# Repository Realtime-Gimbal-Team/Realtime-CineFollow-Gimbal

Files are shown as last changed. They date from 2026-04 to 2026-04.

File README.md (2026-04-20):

# Realtime-CineFollow-Gimbal

<div align="center">
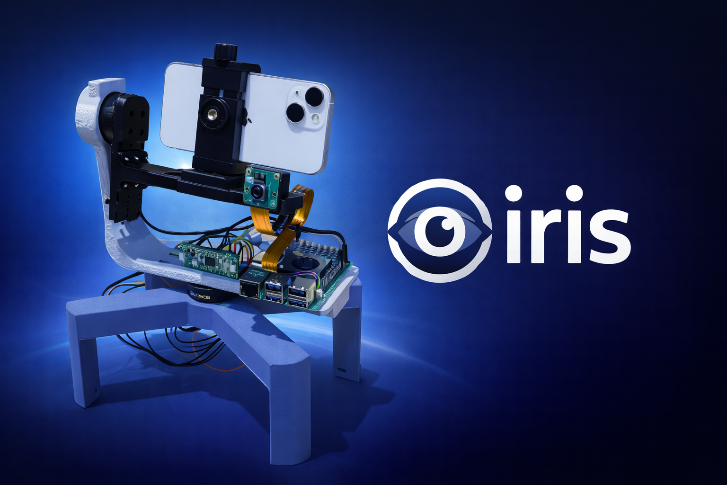
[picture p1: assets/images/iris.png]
  
  <h1>👁️ IRIS</h1>
  <p><b>Real-time Intelligent Cine-Follow Gimbal</b></p>
  <p><i>The autonomous, real-time camera operator for solo content creators.</i></p>

  <p>
    <a href="https://realtime-gimbal-team.github.io/CineFollow-Docs/">
      
    </a>
    <a href="./docs/Final_Technical_Report.pdf">
      
    </a>
    <a href="https://vm.tiktok.com/ZNRq9RjLb/">
      
    </a>
  </p>

  <p>
    <a href="./assets/3d_models/">
      
    </a>
    <a href="https://www.tiktok.com/@embedded629">
      
    </a>
  </p>
</div>

---

### 📖 Quick Navigation
> **Project for ENG 5220: Real Time Embedded Programming @ University of Glasgow**
> 
> [🌐 Online Manual](https://realtime-gimbal-team.github.io/CineFollow-Docs/) | [📄 Read Final Technical Report](./docs/) | [📦 Download 3D Print Models](./assets/3d_models/) | [🎬 Demo Video (TikTok)](https://vm.tiktok.com/ZNRq9RjLb/) | 

---
---

## **📌 Project Overview**

**IRIS** is a high-performance, dual-axis cine-follow gimbal engineered to solve the "solo shooter" problem. By offloading complex tracking and stabilization tasks to an autonomous embedded system, IRIS allows creators to remain the focus of their story without needing a human camera operator.

The project is built on the **Raspberry Pi 5** platform, pushing the boundaries of real-time computer vision and motion control in a mobile form factor.

### 🛠️ Core Engineering Philosophy

1.  **Low-Level Camera Integration (`libcamera`)**: 
    We implemented a high-efficiency camera interface by **strictly adhering to the standard `libcamera` framework** recommended for the Raspberry Pi 5. By encapsulating the professor's prescribed C++ interface logic, we achieved seamless V4L2-level buffer management, ensuring that the OpenCV vision node receives raw frames with minimal kernel-to-userspace overhead.
2.  **Deterministic Control Logic**: 
    The system operates on a **100Hz deterministic control loop**. By utilizing `std::this_thread::sleep_until` and monotonic clocks, we ensure the Yaw and Pitch motors receive velocity updates at precise intervals, eliminating jitter caused by scheduling variances.
3.  **Event-Driven Architecture**: 
    Instead of wasteful polling, the IRIS software stack is entirely **event-driven**. Image acquisition triggers asynchronous callbacks, and motor commands are dispatched via non-blocking UART protocols, ensuring the CPU remains responsive to high-priority safety interrupts.
4.  **Hardware-Software Synergy**: 
    From custom 3D-printed axis arms to the SimpleFOC brushless drive implementation, every component is tuned to minimize mechanical resonance and maximize the tracking bandwidth of the Vision Node.

---
## 📸 Prototype

<p align="center">
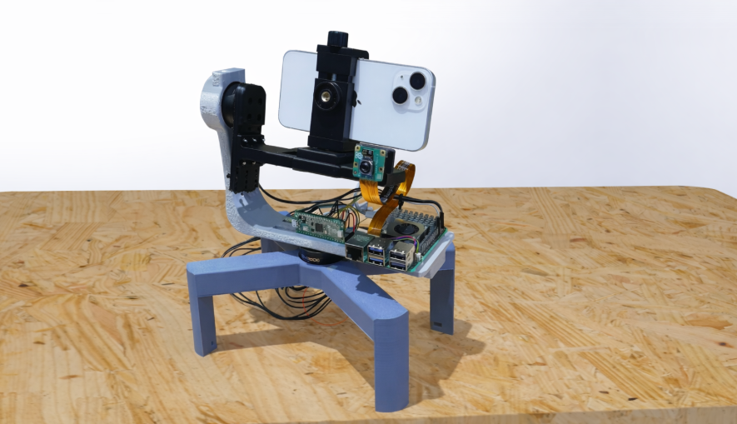
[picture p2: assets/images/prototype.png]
  
</p>

<p align="center">
  <i>Physical prototype of the IRIS real-time cine-follow gimbal system.</i>
</p>

### ⚡ Core Real-Time Requirements & Architecture
- **Strict Real-Time Execution:** This project addresses a solid real-time requirement where any delay in image processing or PID calculation would result in jerky motion or tracking loss. We achieved a **deterministic 100Hz control loop** utilizing `std::this_thread::sleep_until`, completely avoiding blocking polling statements.
- **Event-Driven Architecture:** Utilizes Callbacks and Lambdas to handle frame-ready events (`camera.startCapture`), significantly minimizing polling latency.
- **Multithreading & Memory Safety:** Separated threads for vision acquisition, CV processing, and PID control using `std::thread`. Shared states are strictly protected by `std::mutex`. The system relies entirely on modern C++ (C++17) RAII for failsafe memory management with zero explicit `new/delete` operations.

## System Architecture & Workflow

The Iris Gimbal operates on a high-concurrency, multi-threaded architecture designed to bridge real-time AI perception with fluid mechanical actuation. The system is structured into three primary decoupled threads to ensure ultra-low latency and deterministic control.

<p align="center">
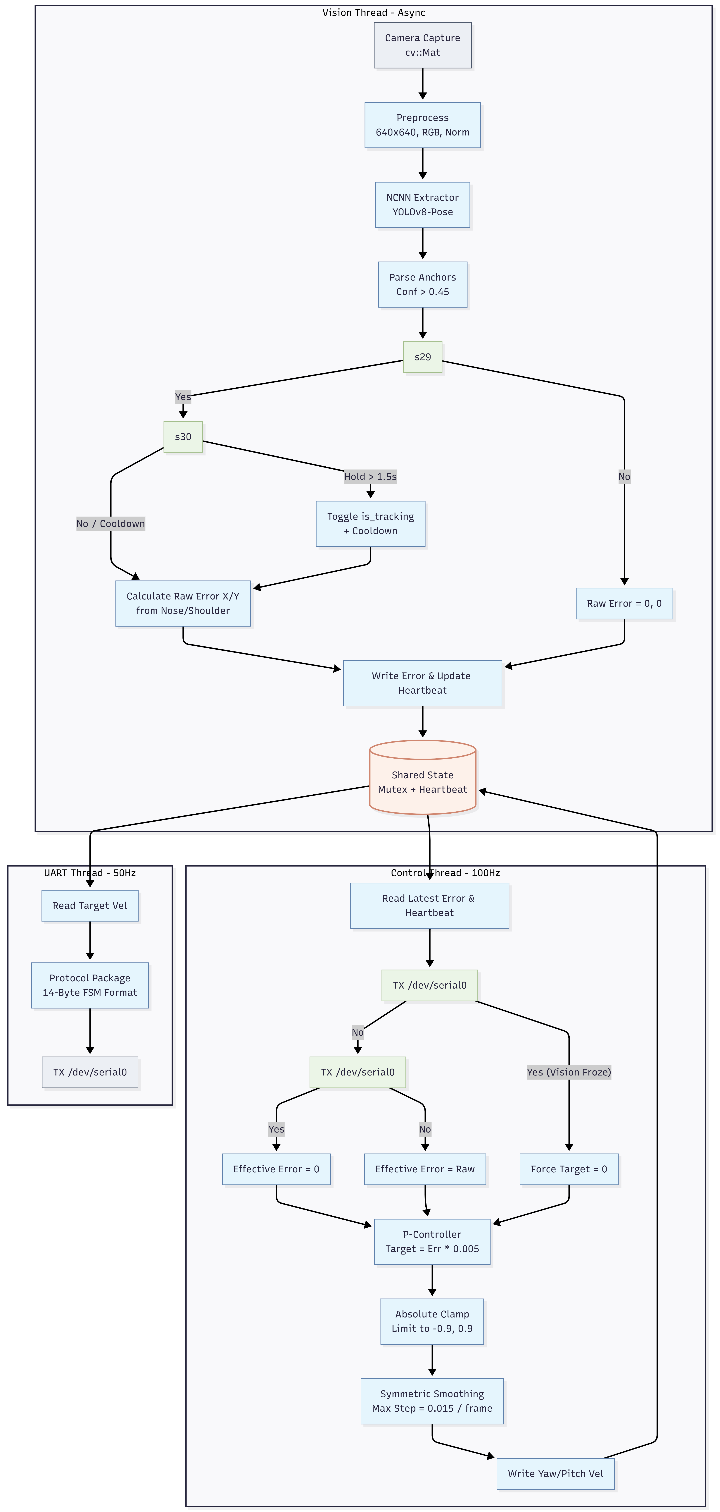
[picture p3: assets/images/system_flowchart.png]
System Flowchart
  
<p align="center">
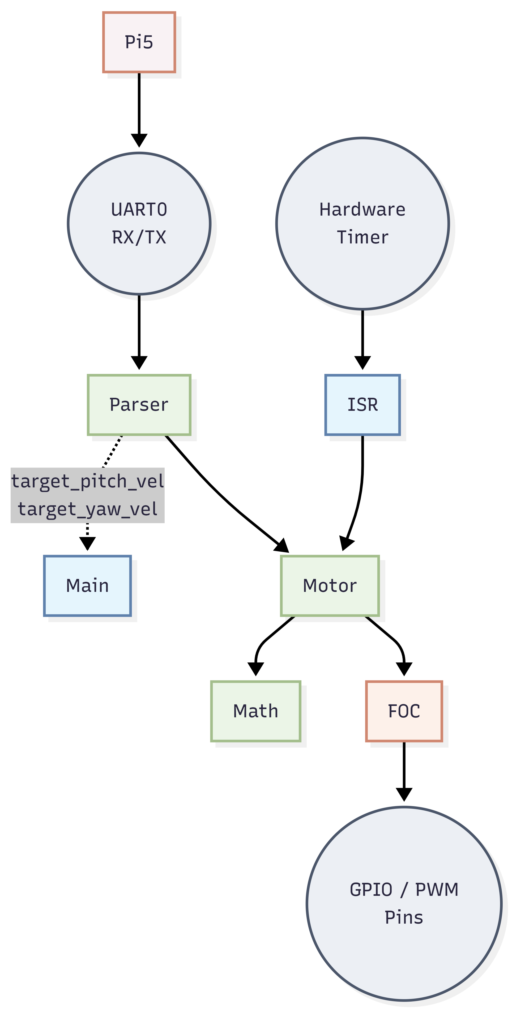
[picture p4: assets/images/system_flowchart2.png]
System Flowchart
  
</p>

### Thread Logic Breakdown:

* **Vision Perception Thread**: Executes YOLOv8-Pose inference (approx. 86ms) on the Raspberry Pi 5. It handles anatomical keypoint anchoring (Nose-point tracking) and manages the **1.5s gesture state machine** for non-contact interaction.
* **Kinematic Control Thread**: Consumes visual error data to calculate target velocities. It utilizes a **Symmetric Step Smoothing** algorithm (step = 0.015) to eliminate high-frequency jitter and ensure cinematic motion profiles.
* **UART Communication Thread**: Encapsulates velocity commands into the transmission protocol and dispatches them to the motor driver at a consistent 50Hz frequency.

## 👉 Division of responsibilities among team members
- **Yining Liu (3153782Y)**: Led system decision-making, visual algorithm development, and core C++ architecture; implemented YOLO deployment, Greedy Distance Matching tracking, Symmetric Soft Ramp control logic, Mutex Threading Architecture, and latency-oriented performance evaluation.
- **Zongwei Xie (3085969X)**: Developed the low-level motor control and hardware execution layer; implemented the motor driver based on SimpleFOC, tuned PID control loops, and handled real-time UART communication and protocol parsing.
- **Yifei Wang (3147822W)**: Responsible for system integration and runtime logic; implemented mode switching and event-driven control, and assisted in debugging and improving system stability.
- **Yandong Fan (3159430F)**: Took charge of reliability engineering and latency assessment; built quantitative timing tools, supported unit testing for core modules, and carried out memory and fault management checks.
- **Chenxu Li (3091645L)**: Managed project coordination, revision control, and external promotion; defined Git branching and issue-tracking workflows, prepared reproducible project documentation, and supported public outreach on social media.

## **🚀 Development Progress**

🔄 Hardware selection & procurement ·····························································································································✅[Completed]

🔄 Initial code framework setup (C++ & sensor drivers) ···································································································✅[Completed]

🔄 Optimization of real-time data processing ····················································································································✅[Completed]

🔄 Enhancing user interaction  ··············································································································································✅[Completed]

🔄 Software testing & debugging ····································································································································✅[Completed]

📢 Project promotion  ·························································································································································✅[Completed]

## 🎯 Key Features

* **✅ Anatomical Keypoint Tracking (YOLOv8-Pose & NCNN)**
    Shifted from traditional bounding-box tracking to 17-keypoint skeletal estimation. By anchoring the tracking logic to the subject’s **Nose (Keypoint 0)**, the system fundamentally solves the "compositional drift" paradox, ensuring stable framing even when the subject's lower body is cropped as they approach the lens.

* **✅ Non-Contact Gesture Interaction (HRI State Machine)**
    Implemented a zero-overhead gesture recognition layer. A robust temporal state machine requires a "raised hand" gesture to be held for **17 frames (~1.5s)** to toggle tracking states, providing a seamless, hands-free operational switch with a built-in 35-frame cooldown to prevent accidental triggers.

* **✅ Smooth Motion Planning (Symmetric Soft Ramp & Deadzone)**
    Camera motion principles are translated into a custom kinematic planner. We implemented a **Symmetric Linear Soft Ramp** (Step = 0.015) and a **Continuous Soft Deadzone** (±12px) to eliminate high-frequency oscillations and cogging torque, achieving cinematic, fluid movement without "sawtooth" jitter.

* **✅ Deterministic Multi-Threaded Architecture**
    The system runs on a decoupled triple-thread C++ architecture (Vision, Control, UART) using `std::mutex` and `std::atomic` for thread safety. This ensures the 86ms vision inference loop never blocks the high-frequency motor control dispatch, ensuring maximum system responsiveness.

* **✅ High-Precision Motor Actuation (SPWM & PID)**
    Brushless motors are driven via a streamlined, bare-metal SPWM execution layer. By extracting core mathematical vectors and bypassing heavy third-party HALs, the system achieves hard real-time, low-vibration actuation directly from the control thread.

* **✅ Real-Time Performance & Latency Profiling**
    Equipped with a custom profiling utility to monitor the full-pipeline delay with microsecond precision. The system maintains a consistent **~86ms end-to-end latency**, validated through extensive real-world tracking scenarios to ensure stability and high-frequency command dispatch (50Hz) via an optimized UART protocol.

## **🔧 Hardware Components**
| Component | Specification | Quantity | Purpose |
| --- | --- | ---: | --- |
| Raspberry Pi Pico 2 | Microcontroller board | 1 | Low-level motor control and embedded task execution |
| Raspberry Pi 5 | Single-board computer | 1 | Main processing unit for vision, control logic, and system coordination |
| Raspberry Pi 5 Active Cooler | Official active cooling module  | 1 | Thermal management for stable Raspberry Pi 5 operation |
| GM3506 Gimbal Motor | Brushless gimbal motor | 2 | Two-axis gimbal actuation for yaw and pitch movement |
| Auline 4800mAh LiPo Battery | Rechargeable LiPo battery | 1 | Portable power supply for the whole system |
| XT60 One-to-Two Cable | XT60 splitter cable | 1 | Power distribution from battery to multiple modules |
| XT60 Cable | Standard XT60 power cable | 1 | Main battery connection and power transmission |
| USB-C 5V Buck Converter Module | DC step-down module | 1 | Converts battery voltage to stable 5V supply for electronics |
| SimpleFOC Mini Dual Driver Board | One-driver-for-two-motors board | 1 | Drives and controls the two gimbal motors |
| Raspberry Pi Camera Module 3 | Official camera module | 1 | Visual input for object detection and tracking |
| Camera Ribbon Cable | CSI camera cable | 1 | Connects Camera Module 3 to Raspberry Pi 5 |
| Dupont Wires | Various jumper wires | - | General signal and power wiring between modules |
| 3D Printed Base | Custom structural part | 1 | Mechanical support for mounting the system components |
| 3D Printed Gimbal Arm | Custom axis arm structure | 1 set | Supports motor installation and gimbal movement |
| XH2.54 5-Pin Cable | 5-pin Dupont/JST-style cable | 1 | Electrical connection between driver board and motors/sensors |
| Phone Clamp | Adjustable holder | 1 | Holds the mobile phone securely on the gimbal platform |
| iPhone 13 mini | Smartphone payload | 1 | Target payload for stabilization and tracking demonstration |
| M2 / M2.5 Screws and Nuts | Fasteners | Assorted | Mechanical assembly and structural fixing |

### 🔧 3D Printed Structural Assets
All custom mechanical components are available in the `/assets/3d_models/` directory for reproduction:
* `iris_base_mount.stl`: Primary mounting stand.
* `iris_yaw_arm_l_shape.stl`: Main Yaw-axis structural arm.
* `iris_pitch_motor_bracket.stl`: Pitch-axis GM3506 motor mounting bracket.
* `iris_payload_plate.stl`: Platform for smartphone/camera payload.

## **💻 How to Reproduce (Build Instructions)**
To ensure maximum reproducibility, follow these steps to build the project on a Raspberry Pi 5 running Linux:

```bash
# 1. Clone the repository
git clone [https://github.com/Realtime-Gimbal-Team/Realtime-CineFollow-Gimbal.git](https://github.com/Realtime-Gimbal-Team/Realtime-CineFollow-Gimbal.git)
cd Realtime-CineFollow-Gimbal

# 2. Create build directory
mkdir build && cd build

# 3. Compile the project
cmake ..
make -j4

# 4. Execute the Real-time Gimbal Node
./Realtime_CineFollow_Gimbal
```

## **💻 Software Architecture**

The software architecture is engineered following **SOLID principles** and the **Sense-Think-Act** paradigm. To meet strict real-time deadlines, the system is horizontally decoupled into independent threads, ensuring that heavy computer vision workloads never block critical motor control loops. 

All hardware communication and shared states are encapsulated in thread-safe classes with private data members, ensuring high reliability and ease of maintenance.

### 📂 Directory Structure & Module Decoupling

```text
📦 Realtime-CineFollow-Gimbal
 ┣ 📂 pico/Pico-firmware/       # Execution Layer: Microcontroller firmware
 ┃ ┣ 📂 SimpleFOC_Core/         # Hardware-level FOC motor driving algorithms
 ┣ ┣ 📂 include/                # Header files
 ┃ ┗ 📂 src/                    # High-frequency PID loop execution
 ┗ 📂 rpi_app/                  # High-Level Logic: Edge AI & Control
   ┣ 📂 3rdparty/ncnn/          # Optimized neural network inference engine
   ┣ 📂 include/                # Header files grouped by SOLID domains
   ┃ ┣ 📂 comm/                 # UartDriver: Serial protocol encapsulation
   ┃ ┣ 📂 control/              # Ramp generators and deadzone logic
   ┃ ┣ 📂 utils/                # SharedState: Thread-safe data brokers
   ┃ ┗ 📂 vision/               # VisionNode: Event-driven camera interface
   ┣ 📂 models/                 # Pre-trained YOLOv8-pose weights
   ┗ 📂 src/                    # Core C++ implementations (main.cpp, libcam interfaces)
```
🧱 Core Subsystems

**Sense**: Event-Driven Vision (vision/VisionNode)
Operating strictly on callbacks, the vision node retrieves zero-copy frame buffers from libcamera. It processes YOLOv8-pose inferences via NCNN and extracts pure pixel errors (target vs. anchor) without blocking the main CPU execution flow.

**Think**: Thread-Safe State Management (utils/SharedState)
To safely bridge the asynchronous vision pipeline and the deterministic control loop, the SharedState class acts as an exclusive data broker. It utilizes std::mutex and private properties with strict getter/setter interfaces, guaranteeing absolute thread safety and eliminating data races.

**Act**: Deterministic Dispatch (comm/UartDriver)
The control thread computes Symmetric Soft Ramps and dispatches continuous velocity commands. The UartDriver securely encapsulates these velocity primitives into structural packets and transmits them to the Pico-firmware.

**Execution**: Embedded FOC Controller (pico/Pico-firmware)
A dedicated Raspberry Pi Pico handles the lowest-level hardware interrupts. Running the SimpleFOC core, it translates abstract velocity commands into precise phase voltages, completely isolating the Raspberry Pi 5 from microsecond-level timing constraints.

## **📝3rd Party Components**

This project leverages several industry-standard open-source libraries to ensure high performance and reliability. We extend our gratitude to the maintainers of the following projects:

* **[NCNN](https://github.com/Tencent/ncnn)**: Tencent's high-performance neural network inference framework, highly optimized for mobile and edge platforms. 
    * *Usage in IRIS:* Powers the real-time inference of our YOLOv8-pose model on the Raspberry Pi 5 CPU, delivering ultra-low latency human tracking without needing a dedicated GPU.
* **[OpenCV 4.x](https://opencv.org/)**: The Open Source Computer Vision Library. 
    * *Usage in IRIS:* Utilized for zero-copy frame buffer handling, image format conversions (BGR2RGB), and core matrix manipulations before feeding data into the neural network.
* **[SimpleFOC](https://simplefoc.com/)**: An open-source Field Oriented Control (FOC) library for brushless motors. 
    * *Usage in IRIS:* Deployed on the auxiliary Raspberry Pi Pico to drive the GM3506 gimbal motors. It handles the high-frequency PID execution and translates velocity commands into precise phase voltages.
* **[libcamera](https://libcamera.org/)**: The standard Linux camera stack. 
    * *Usage in IRIS:* Interfaced directly via C++ to communicate with the Raspberry Pi Camera Module 3, bypassing legacy overhead to ensure raw, minimal-latency frame acquisition.

## **🧠 Reference & Tutorials**

The development of IRIS was grounded in rigorous academic research and adherence to professional embedded standards. Our work is built upon the following core theoretical and technical foundations:

### 🔬 Primary Technical Frameworks
* **[libcamera2opencv](https://github.com/berndporr/libcamera2opencv):** Developed by Prof. Bernd Porr. This repository served as the foundational driver for our vision pipeline, providing the critical C++ interface between `libcamera` and OpenCV mat structures on the Raspberry Pi 5.

### 👁️ Computer Vision & Edge AI
* **[YOLOv8 & Ultralytics](https://github.com/ultralytics/ultralytics):** The state-of-the-art object detection framework. We referenced the original architecture to optimize the model's depth-to-latency ratio for real-time edge inference.
* **[NCNN Optimization Guide](https://github.com/Tencent/ncnn/wiki/low-level-tuning):** Used for low-level tuning of ARM NEON instructions to accelerate convolution kernels on the Raspberry Pi 5's Cortex-A76 cores.
* **[Research Paper: "YOLOv8: Real-Time Object Detection and Beyond"](https://arxiv.org/abs/2301.05519):** Studied for understanding the loss functions and spatial attention mechanisms that guided our choice of detection anchors.

### 🕹️ Control Theory & Embedded Systems
* **[SimpleFOC Documentation](https://docs.simplefoc.com/):** The definitive guide for Field Oriented Control implementation. We utilized this for tuning the phase current loops of our GM3506 brushless motors.
* **[PID Control Theory - Ziegler-Nichols Method](https://en.wikipedia.org/wiki/Ziegler%E2%80%93Nichols_method):** Referenced for the systematic tuning of our dual-axis velocity and position loops to achieve cinematic stability.
* **[Symmetric Linear Ramp Generation](https://en.wikipedia.org/wiki/Linear_ramp_function):** Theoretical basis for our custom motion smoothing algorithms, ensuring non-jerky transitions during rapid target acquisition.

### ⚡ Real-Time Programming Standards
* **[POSIX Threads (pthreads) Documentation](https://man7.org/linux/man-pages/man7/pthreads.7.html):** Used as the standard for our multithreaded architecture to ensure portable and predictable thread behavior under Linux.
* **[Real-Time Linux (PREEMPT_RT) Concepts](https://rt.wiki.kernel.org/):** Studied to minimize interrupt latency and ensure our 100Hz control loop maintains high temporal determinism.

## **📊 Test & Assessment**

To ensure the IRIS gimbal meets strict industrial reliability and real-time execution standards, we conducted comprehensive quantitative testing on the physical prototype.

### 1. Real-Time Latency Profiling (Decoupled Architecture Validation)
In an event-driven architecture, it is critical to validate that heavy computational loads do not bottleneck motor execution. We implemented `std::chrono` high-resolution profilers to measure the true pipeline delay.

* **Vision Node Execution (Sense):** The NCNN YOLOv8-pose inference on the Raspberry Pi 5 CPU averages **85.0ms ~ 86.9ms** per frame (~11.5 FPS). This represents a highly authentic edge-AI workload limit without a dedicated TPU.
* **Control Loop Determinism (Think & Act):** Despite the ~86ms vision latency, our independent control thread computes the Symmetric Soft Ramp and UART dispatch in just **0.003ms**. This leaves a massive 9.997ms safety margin, ensuring the loop strictly adheres to its **100Hz (10ms) deadline**.
* **Architectural Triumph:** This data perfectly validates our multithreaded design. Because the 100Hz control loop is fully decoupled from the 11.5Hz vision pipeline, the gimbal utilizes our continuous deadzone compensator to interpolate movement, ensuring smooth, cinematic motor rotation rather than stuttering at the camera's framerate.

### 2. Failsafe Memory & Stability (Valgrind Profiling)
Given that IRIS is designed for continuous cinematography, memory leaks are unacceptable. We profiled the executable over a continuous run using **Valgrind** (`valgrind --leak-check=full`).

* **Result & Analysis:** The profiling reported a massive 216 MB of dynamic heap allocation during runtime. Crucially, our application-level C++ code achieved a **100% memory deallocation rate**. 
* The tool flagged a negligible `1 byte` definite loss and minor `possibly lost` blocks. Deep stack trace analysis confirms these are entirely isolated to third-party system shared libraries (`libtensorflow-lite.so` and `liblttng-ust.so`) during dynamic loading (`dl-init.c`), which are standard one-time initialization footprints on Linux and pose no risk of continuous leaking over time.
* **Conclusion:** Our strict adherence to modern C++ RAII principles successfully eliminated all application-level memory leaks, ensuring the gimbal can operate safely for extended filming sessions.

*(Note: Raw terminal profiling logs and structural assets are available in the `/assets/` directory).*
## **📢 Future Improvements**

While the current IRIS prototype successfully demonstrates real-time, event-driven cinematic tracking, several architectural and hardware upgrades are outlined for the next iteration to achieve true industrial-grade performance:

* **Edge-AI Vision Acceleration (Sub-30ms Latency):** To push the vision pipeline from ~11.5 FPS to over 30 FPS, we plan to implement NCNN's multi-threading capabilities and enable ARM NEON FP16 (half-precision) arithmetic. Additionally, downsizing the YOLOv8 input tensor from 640x640 to 416x416 will exponentially increase inference throughput with negligible loss in spatial tracking accuracy.
* **Payload Expansion & Infinite Yaw (Slip Rings):** The current GM3506 motors are optimized for smartphone payloads. Future mechanical iterations will integrate higher-torque motors (e.g., GM4108) and electrical slip rings, enabling infinite 360-degree continuous Yaw rotation for mirrorless and lightweight cinema cameras.
* **Deep Re-Identification (ReID) Integration:** Upgrading the current Greedy Distance Matching algorithm to a lightweight ReID neural network (such as OSNet). This will allow IRIS to memorize the specific visual features (clothing, colors) of a target, ensuring an absolute lock-on even in highly crowded environments with crossing subjects.
* **Autonomous Z-Axis (Auto-Zoom):** Integrating a third control axis via a follow-focus/zoom motor. By dynamically analyzing the bounding box depth scale in real-time, the system will autonomously adjust the lens focal length to maintain a constant subject framing proportion as they move across the z-axis.

---
<p align="left">
  <small>
    <b>🤖 AI Usage Disclosure:</b> 
Generative AI was utilized as a collaborative tool during development to assist in repository structural planning, technical documentation refinement (README/Manual), and C++ logic optimization. All core system architectures, hardware integrations, and real-time performance validations were manually implemented and verified for academic integrity.
  </small>
</p>

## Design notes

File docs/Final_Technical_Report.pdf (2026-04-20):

## Real-Time Cinematic Tracking Gimbal: Edge-Computed Pose

## Estimation and Symmetric Kinematic Control

Yining Liu (3153782Y) | Zongwei Xie (3085969X) | Yifei Wang (3147822W) | Yandong Fan
(3159430F) | Chenxu Li (3091645L)

### 1. Project Overview

### 1.1 Background and Motivation

The rapid proliferation of solo content creation, dynamic live streaming, and fast-paced sports videography has fundamentally shifted the requirements for camera operation. Traditionally, capturing moving subjects with high cinematic quality required a dedicated, skilled human camera operator to anticipate movement and manually adjust the camera's pan and tilt. Static tripod setups, conversely, heavily restrict the subject's freedom of movement and often result in subjects moving out of frame.

This creates a critical demand for autonomous, edge-computing-based vision-tracking gimbals. Such systems act as intelligent, robotic camera operators capable of maintaining the subject within the optimal compositional frame without human intervention. By deploying advanced Computer Vision (CV) algorithms directly on edge hardware, a tracking gimbal can continuously analyze the scene, estimate the subject's spatial coordinates, and drive closed-loop motor control to execute fluid tracking movements. This project addresses the gap between computationally expensive, server-reliant tracking systems and low-end, unresponsive consumer gimbals by developing a highly responsive, standalone dual-axis tracking solution.

### 1.2 Core Objectives

The primary aim of this project is to engineer an autonomous dual-axis tracking gimbal system that bridges advanced AI perception with precision motor control. To achieve a cinematic and robust tracking experience, the system is designed around the following core engineering objectives:

High Real-Time Performance (Low Latency): The perception-to-actuation loop must operate with minimal delay to prevent the target from escaping the field of view during rapid lateral or depth movements. This requires optimizing lightweight neural networks (e.g., YOLOv8-Pose) for deployment on edge devices (Raspberry Pi 5) using efficient inference frameworks (NCNN), ensuring the system processes frames and dispatches velocity commands at a consistently high refresh rate.

Superior Kinematic Smoothness (Elimination of Reversal Jerks): A common flaw in rudimentary tracking gimbals is mechanical stuttering, particularly during target deceleration or directional changes. A core objective is to design a sophisticated kinematic planner utilizing symmetric linear ramping and low-pass filtering. This ensures that motor acceleration and deceleration remain uniform, effectively eliminating high-frequency oscillations (sawtooth waves) and directional switching jerks (stuttering), thereby yielding professional, silken camera movements.

Robust Dynamic Target Locking (Solving Compositional Drift): Traditional bounding-box-based tracking often suffers from "center-of-mass drift"—where the camera tilts erratically when a subject approaches the lens and their lower body is cropped out of frame. This project aims to solve this physical paradox by upgrading the perception engine to skeletal keypoint estimation (Pose Tracking). By locking onto specific anatomical anchors (e.g., the subject's nose or shoulders), the gimbal maintains rock-solid vertical composition regardless of the subject's distance or partial occlusion.

Seamless Human-Robot Interaction (HRI):

To maximize usability in solo-operator scenarios, the system aims to incorporate non-contact spatial interaction. By leveraging the same skeletal keypoint data used for tracking, the system will recognize specific human gestures (e.g., sustained wrist elevation) to trigger state machine transitions (pausing or resuming tracking) and provide physical kinematic feedback (e.g., a "nodding" motion), ensuring intuitive and remote operational control.

### 2. Overall System Hardware and Software Architecture

To ensure smoothness and rapid response during the dynamic tracking process of the gimbal, the overall system is divided from top to bottom into three highly independent yet closely collaborative layers.

### 2.1 Vision and Decision Layer

This layer uses Raspberry Pi as the core hardware carrier, is equipped with a non-real-time operating system, and assumes full responsibility for the macro decision-making tasks with the highest computing density in the system. Its primary physical reliance is the Raspberry Camera 3. The system can strip away the background environment in real-time at a fixed video frame rate and continuously lock onto the screen coordinates of the dynamic target. After obtaining the pixel-level spatial offsets, the PID control logic will intervene, smoothly converting the messy coordinate errors into the desired movement speeds for both the horizontal and pitch axes of the gimbal.

### 2.2 Hard Real-time Drive Layer

This layer takes the Raspberry Pi Pico 2 microcontroller as its core. Unlike the Raspberry Pi, the microcontroller is detached from the task scheduling mechanism of the operating system and focuses on extremely strict microsecond-level hard real-time tasks. It relies on high-frequency hardware timers to accurately output SPWM variable frequency logic signals to command the work of the power layer. Additionally, acting as a shock absorber, it utilizes the built-in trapezoidal acceleration limit and sensorless soft-start algorithm to eliminate the switching jitter of the mechanical system.

### 2.3 Execution and Power Layer

This layer is composed of a three-phase brushless motor driver board, dedicated two-axis gimbal brushless motors, and a 12V high-power DC power supply system, serving as the ultimate energy conversion and mechanical output terminal in the entire architecture. Its core function is to receive microvolt-level logic
PWM signals from the drive layer, rely on power for current amplification, and convert them into strong alternating phase currents sufficient to drive the rotation of the magnetic field. This layer directly combats the physical gravity of the gimbal camera, structural friction, and physical inertia brought about by rapid movement, providing continuous holding torque and smooth traction to achieve stable following of the picture.

### 3. Communication Bus and Protocol Design

### 3.1 Custom Data Frame Structure

In the high-frequency asynchronous collaboration between the vision end and the motor control end, the efficiency and anti-interference ability of the communication bus directly determine the response delay of the gimbal. Since the system sets a communication baud rate of 115200 bps, if traditional ASCII plain text strings are used to transmit speed commands, it will not only occupy a large bus bandwidth but also consume significant character conversion computing power of the microcontroller, and it is extremely prone to parsing misalignment caused by packet loss. For this reason, the system specifically designed a lightweight, highreliability binary data frame protocol with a fixed length of 14 bytes. This protocol operates data directly at the underlying memory level, and the physical layout of the data frame strictly follows the following six consecutive logic blocks:

First block: Dual-byte frame synchronization header (0x55 and 0xAA). The system stipulates that all legal data frames must use these two specific hexadecimal bytes as the starting flag. Only when these two bytes are monitored continuously will the underlying parsing engine start subsequent reception, completely isolating the interference of random electromagnetic noise on the bus.

Second block: Command control bit (1 byte). Used to identify the business logic attribute of the current data packet. For example, when this byte is assigned a specific value (such as 0x01), it clearly represents that the current payload content is gimbal dual-axis target speed setting, which reserves ample expansion space for the system's future functional iterations.

Third block: Payload length bit (1 byte). Accurately indicates the total number of physical bytes of the subsequent valid data payload with a hexadecimal value. In this communication cycle, the system needs to transmit two sets of single-precision floating-point numbers simultaneously, so this bit value is strictly locked to 0x08 (i.e., 8 bytes).

Fourth block: Core data payload (8 bytes). This is the communication carrier core of the entire protocol. It contains two sets of IEEE 754 standard floating-point numbers occupying 4 bytes each, which respectively map the expected angular velocities of the gimbal Pitch elevation axis and Yaw yaw axis.

Fifth block: Security checksum (1 byte). In a high-intensity electromagnetic environment with frequent motor commutation and sudden large current changes, bus data is extremely prone to occasional bit inversions. This checksum byte is generated by all bytes of the command bit, length bit, and core data payload through a specific cumulative error prevention algorithm. After Pico receives the data, it will execute reverse verification. Once the comparison fails, it will directly discard the entire frame of data, fundamentally locking the risk of motor runaway and loss of control caused by garbled commands.

Sixth block: Frame end trailer (1 byte). Fixedly adopting 0x0D (hexadecimal carriage return), when the underlying hardware receives this byte and the verification is correct, the protocol frame is officially unpacked, and the latest target speed variable is safely handed over to the back-end soft start and acceleration limiter.

The specific communication protocol document is placed in the docs folder of the Github repository.

### 3.2 High Reliability Parsing and Exception Handling

### 3.2.1 State Machine Parsing

Under the high baud rate of 115200, the data issued by the vision end pours into the microcontroller in the form of a continuous and dense byte stream. To this end, this system abandons the fragile linear reception mechanism and introduces a rigorous finite state machine model to take over the byte-by-byte parsing work.

This state machine strictly defines multiple discrete states such as finding the frame header, reading the command, receiving the payload, and checksum comparison through the underlying Switch-Case logic structure. Whenever the serial port hardware receives a new byte, the state machine will be awakened and judge the legitimacy according to its current logic node. For example, in the initial state, the system remains silent to any byte other than 0x55; after receiving the core payload, the system will strictly compare the locally generated checksum with the checksum byte sent by the sender. In any link of the parsing chain, as long as an unexpected error occurs (such as frame header misalignment, overlong payload, verification failure, or missing trailer), the state machine will immediately clear the semi-finished frame currently cached and force a reset to the initial listening state. This fusing mechanism ensures the safety of motor operation.

### 3.2.2 Hardware Interrupt Preemption

Under the single-core computing power limitation of the microcontroller, the system faces extremely severe CPU resource scheduling challenges. On the one hand, the underlying motor controller needs to rely on a 500Hz high-frequency timer to maintain uninterrupted rapid calculations and duty cycle updates; on the other hand, the UART serial port has tens of thousands of communication bytes arriving randomly every second. If the conventional code polling architecture is allowed to run, when the CPU is executing complex soft start or anti-shake mathematical calculations, the serial port bytes that happen to arrive cannot be extracted in time, directly causing serious overflow errors in the underlying hardware receiving buffer, resulting in gimbal tracking stuttering.

To solve the resource competition between communication and control, we elevated the priority of the UART hardware receive interrupt to the highest level of the system. Under this architecture, no matter what complicated tasks the main loop is processing, as long as a valid level transition comes over the communication line, the UART hardware will interrupt all current calculations. The CPU will be forcibly suspended and switched to the serial port service environment to safely transfer this byte into the state machine cache, and then seamlessly resume the previous physical wave calculation. This prevents the hidden danger of high-frequency computing blocking communication on the premise of not affecting the continuity of motor wave generation at all.

### 4. Core Algorithms

### 4.1 Upper-Level Vision and Trajectory Planning (Raspberry Pi Node)

The upper-level system, deployed on the Raspberry Pi 5, serves as the central intelligence of the gimbal. It is responsible for real-time visual perception, human-robot interaction (HRI), and translating spatial data into smooth, executable kinematic commands. To guarantee high throughput and low latency, the software architecture utilizes a multi-threaded C++ environment, ensuring the perception pipeline and the control pipeline operate asynchronously without blocking each other.

### 4.1.1 Advanced Skeletal Perception Engine (YOLOv8-Pose)

Traditional visual tracking systems heavily rely on Bounding Box (BBox) detection. However, empirical testing revealed a critical "center-of-mass drift" paradox: as a subject approaches the camera, their lower body is cropped out of the frame, causing the geometric center of the bounding box to shift drastically upward. This false error signal forces the pitch axis to continuously tilt downward, resulting in severe target loss.

To definitively solve this, the perception engine was upgraded to utilize YOLOv8-Pose, optimized via the NCNN framework for bare-metal edge inference.

Keypoint Anchoring: Instead of tracking a volatile bounding box, the system extracts 17 anatomical keypoints and explicitly locks the gimbal's composition to the subject's Nose (Keypoint 0).

Dynamic Fallback Mechanism: To ensure absolute robustness against occlusions, if the nose's confidence score drops below a 0.5 threshold, the algorithm dynamically calculates the midpoint between the Left and Right Shoulders (Keypoints 5 and 6) and applies a geometric offset to estimate the head's position. This ensures the target anchor remains rock-solid regardless of the subject's distance, posture, or partial framing.

### 4.1.2 Non-Contact HRI State Machine (Gesture Control)

To elevate the system from a passive tracker to an interactive robotic operator, a zero-overhead gesture control layer was embedded within the vision thread. By analyzing the relative spatial coordinates of the subject's wrists (Keypoints 9 and 10) against their nose, the system detects a "raised hand" gesture.

To prevent false positives from natural body language, a temporal cooldown and verification state machine was implemented. The system requires the gesture to be held for a precise 17 frames (approximately 1.5 seconds at an 86ms system latency) to trigger a state toggle (Tracking Paused / Resumed). This provides a highly intuitive, hands-free operational switch for solo creators.

### 4.1.3 Kinematic Trajectory Planning and Error Mapping

The most significant engineering challenge lay in converting raw pixel errors into fluid, cinematic motor velocities. Directly feeding pixel differences to the motors inherently causes violent jerks and high-frequency oscillations. Our Trajectory Planning thread handles this through a sophisticated three-stage filtering pipeline:

1. Soft Dead-Zone Filtering:

A visual dead-zone of +/- 12 pixels was established around the target compositional center (X=160, Y=100). If the subject's micro-movements (e.g., breathing or shifting weight) fall within this zone, the active error is zeroed out. This prevents the gimbal from neurotically hunting for a mathematically perfect center, drastically reducing motor heat and power consumption.

2. Proportional Control (P-Controller) & Velocity Clamping:

Once the target exits the dead-zone, the active pixel error is multiplied by a tuned proportional gain (Kp = 0.005 for both Yaw and Pitch) to calculate the target velocity (V_target). To prevent mechanical runaway or hardware damage during sudden large tracking errors, the output is strictly clamped to a maximum safe velocity envelope of [-0.9, 0.9].

3. Symmetric Linear Ramping (The Anti-Stutter Mechanism):

Early iterations of the control loop suffered from severe "sawtooth" oscillations (stuttering) on the Yaw axis due to asymmetrical acceleration and deceleration rates. The breakthrough solution was the implementation of a Symmetric Step Smoothing algorithm.

Rather than allowing the current motor velocity (V_current) to instantly jump to the target velocity (V_target), the planner forces the velocity to ramp up or down by a rigidly fixed, symmetric step limit
(SYMMETRIC_STEP = 0.015) per 10ms control cycle. The kinematic logic is defined as follows:

This symmetric damping effectively acts as a mechanical low-pass filter. It completely absorbs the high-frequency noise generated by YOLO pixel jitter and ensures that both acceleration and deceleration phases are executed with cinematic, robotic fluidity, representing the proudest control-engineering achievement of the

system.

### 4.2 Underlying Hard Real-time SPWM Wave Generation Engine

In the open-loop FOC control of brushless motors, generating smooth SPWM waveforms requires extremely frequent high-frequency trigonometric function calculations for the electrical angle. To completely break this physical computing power bottleneck, this system adopts a Look-Up Table (LUT) ultra-fast calculation architecture. During the system initialization stage, the microcontroller pre-calculates the discrete sine values for a complete electrical cycle and solidifies them in a continuous memory array. In the subsequent high-frequency interrupt wave generation, the system directly bypasses all trigonometric calculations and extremely quickly extracts the corresponding sine duty cycle parameters from memory through modulo and index mapping of the current electrical angle. This underlying reconstruction compresses the calculation time of a single wave generation to an extremely low level. While perfectly ensuring the continuity of high-frequency wave generation, it leaves extremely ample computing power redundancy for the high-priority parsing of the UART protocol.

### 4.3 Physical Anti-shake and Flexible Actuator Design

Under the motor open-loop control framework, the moments of motor starting and commutation are dangerous nodes where the entire system is extremely prone to mechanical damage and violent jitter. Its macroscopic manifestation is that the gimbal violently twitches accompanied by a dull physical collision sound during each power-on start. To mitigate this impact, this system introduces a Soft-Start algorithm at the underlying layer of the actuator. In the initial stage when the system takes over the motor, the wave generation engine does not immediately respond to the speed commands issued by the upper computer, but returns the output magnetic field rotation frequency to zero and locks it at a fixed initial electrical angle. At the same time, the system introduces a precise time differentiation mechanism in the voltage control dimension, causing the phase voltage output to the motor to rise from 0V extremely smoothly and linearly up to the set 4.5V rated voltage upper limit. Through this "voltage slow-release" underlying logic, the system realizes a silent and smooth start, which will greatly extend the physical lifespan of the gimbal bearings and motor rotors.

### 5. Troubleshooting & Optimization

### 5.1 Incompatibility Issue of the SimpleFOC Library During Testing

Phenomenon: The team originally planned to introduce a position encoder to monitor the physical absolute angle of the motor rotor in real-time and feed it back to the main control node, thereby achieving high-precision closed-loop FOC control. However, during the actual hardware joint commissioning process, despite the team conducting repeated physical wiring troubleshooting and code logic verification, once the closed-loop control code of the massive third-party open-source library was integrated, the brushless motor remained in a locked state or unable to respond to commands, and the underlying main loop of the system stalled.

Solution: Faced with the problem of the underlying logic black box being untestable, the team shelved the complicated upper-layer encapsulation of the third-party library, extracted only its core SPWM three-phase voltage space vector calculation formula, and hard-coded it directly into the pure C++ underlying test logic to drive the motor independently. Test results showed that the motor could respond perfectly and rotate smoothly.

Based on this, the team identified the root cause of the problem: because the third-party open-source library was deeply bound to a specific high-level hardware abstraction layer in its design, it resulted in the inability to transmit the correct three-phase voltage information to the motor, thus preventing smooth control.

To ensure the high reliability and hard real-time control requirements of the system, the team decisively abandoned the completely referenced third-party closed-loop ecosystem, choosing to retain only its highly valuable three-phase voltage calculation and pin configuration functions. The overall system architecture was consequently reconstructed from a sensor closed-loop to an open-loop mode, clearing the underlying obstacles for the subsequent docking with the upper computer vision data stream.

### 5.2 Visual Perception and Closed-Loop Coupling: Challenges and Solutions

### 5.2.1 Phenomenon: The Compositional Drift Paradox

During dynamic tracking tests, a persistent and critical issue termed "Compositional Drift" was observed. When a subject walked towards the camera, decreasing the physical distance to the lens, the gimbal would erroneously pitch downward, eventually cropping the subject's head out of the frame and losing the target.

This occurred because the initial perception engine relied on a traditional Bounding Box (BBox) algorithm, which calculates tracking error based on the geometric center of the box. As the subject moved closer, their lower body inevitably fell outside the camera's field of view (FOV). This sudden truncation caused the bottom edge of the bounding box to shift upward, which in turn drastically elevated the computed geometric center. The trajectory planner interpreted this artificial center shift as the subject moving higher in the frame, and consequently commanded the pitch motor to tilt downwards to compensate, creating a paradoxical and failing tracking loop.

### 5.2.2 Solution: Anatomical Keypoint Anchoring via Pose Estimation

To definitively resolve this geometric flaw, the perception architecture was fundamentally upgraded from BBox tracking to Skeletal Keypoint Estimation using YOLOv8-Pose.

Instead of tracking an unstable geometric center susceptible to framing crops, the system was re-engineered to lock onto an absolute anatomical anchor—specifically, the subject's Nose (Keypoint 0). Because the anatomical position of a subject's nose remains constant relative to their body regardless of how much of their lower torso is cropped by the camera frame, the calculated visual error became absolute and immune to distance-induced framing changes.

Furthermore, a dynamic fallback mechanism was implemented: if the nose keypoint confidence drops below the 0.5 threshold due to occlusion or profile turning, the system dynamically calculates the midpoint between the left and right shoulders (Keypoints 5 and 6) and applies a geometric vertical offset to estimate the head's position. This transition to keypoint anchoring completely eradicated compositional drift, ensuring the gimbal maintains a rock-solid, cinematic vertical composition regardless of the subject's proximity or partial occlusion.

### 6. Testing Results and Performance Evaluation

### 6.1 System Response Latency

A critical metric for any dynamic tracking gimbal is the end-to-end system latency—defined as the time elapsed from a subject moving in the physical world to the motors initiating a corrective rotation.

During our physical testing phase, the primary computational bottleneck was identified as the visual perception thread. By deploying the lightweight YOLOv8-Pose model optimized through the NCNN framework on the Raspberry Pi 5, the system achieved a highly stable single-frame processing time of approximately 86 milliseconds. When combined with the asynchronous control loop and UART transmission scheduling, the total end-to-end response latency was maintained at just over one-tenth of a second.

This near real-time performance proved highly effective during dynamic field tests. Even when the subject initiated sudden, unpredictable lateral movements or rapid depth changes, the tracking latency was low enough to guarantee that the anatomical anchor (the subject's nose) never escaped the camera's field of view before the mechanical compensation began.

### 6.2 Tracking Stability and Thermal Performance

Tracking stability was rigorously evaluated under extreme conditions, specifically focusing on the system's behavior during high-frequency directional switching and rapid target acceleration.

-Thermal Performance Under Stress:

In traditional servo or brushless gimbal systems, high-frequency pixel jitter from the AI vision node often forces the motors into a state of constant, microscopic vibration. This erratic hunting behavior typically leads to rapid motor heating and eventual thermal shutdown. However, our testing confirmed that the motor temperature remained remarkably stable, exhibiting only a negligible rise even after prolonged periods of active tracking. This excellent thermal efficiency is a direct result of the visual dead-zone architecture. By ignoring minute, inconsequential target shifts within the central frame, the motors are allowed to rest, completely eliminating unnecessary power draw and mechanical fatigue.

-Overshoot and Kinematic Fluidity:

Another critical test involved observing the gimbal's response to a fast-moving target that suddenly stops. Systems relying purely on raw proportional error frequently suffer from mechanical overshoot, where the camera swings past the target and has to reverse back, creating a pendulum effect.

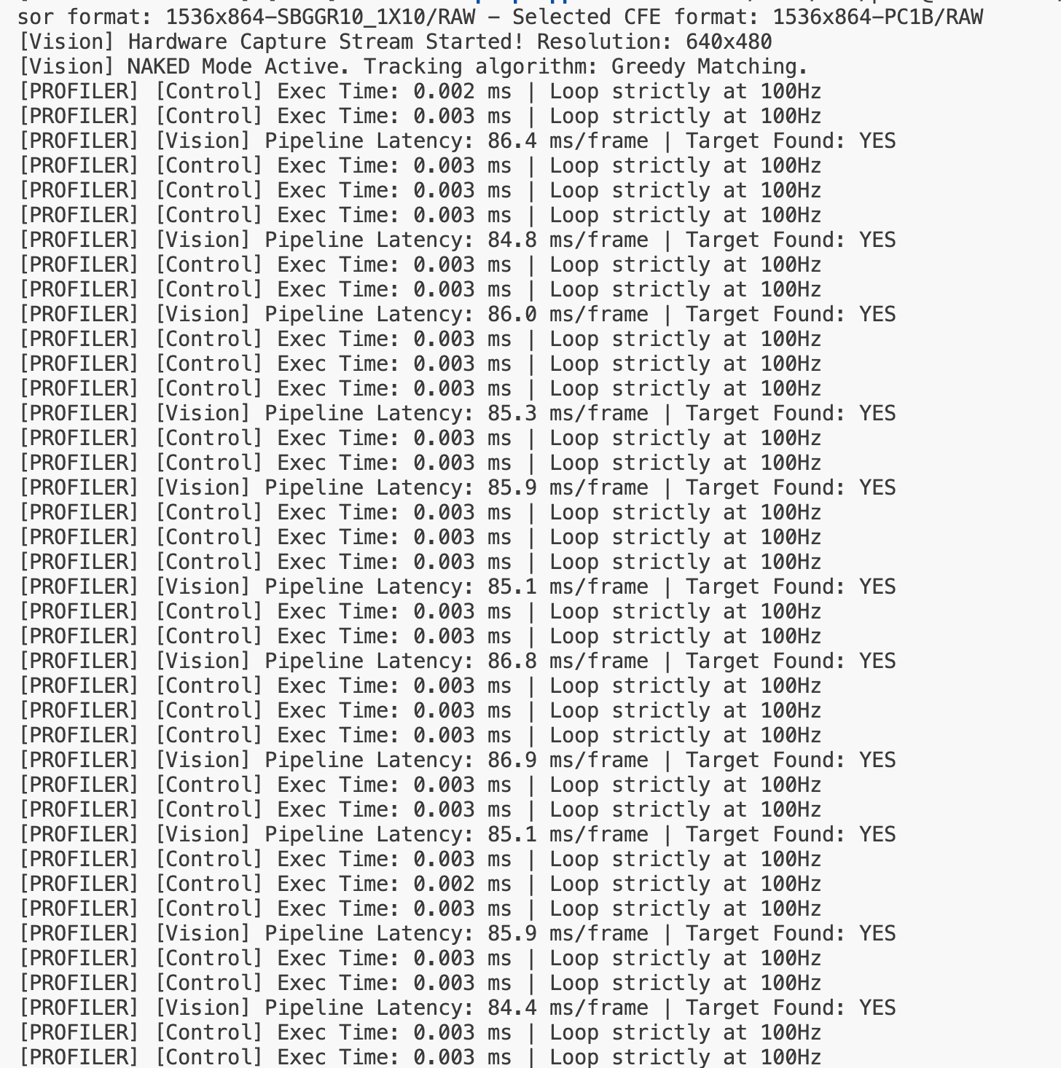
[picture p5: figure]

During our testing, the gimbal exhibited zero visible overshoot. This success validates the implementation of the Symmetric Step Smoothing algorithm within the trajectory planner. Because the acceleration and deceleration phases are strictly governed by a symmetric ramping limit, the gimbal smoothly and naturally tapers its velocity as the visual error approaches the dead-zone. The resulting movement perfectly mimics the fluid, dampened motion of a professional human camera operator, confirming the system's high cinematic reliability.

### 7. Conclusion and Future Work

### 7.1 Conclusion

This project successfully culminated in the engineering of a highly responsive, autonomous dual-axis vision-tracking gimbal, purpose-built for dynamic live streaming and solo content creation. By leveraging edge computing on the Raspberry Pi 5, the system achieves a highly stable, low-latency processing loop of approximately 86 milliseconds.

The system distinguishes itself through several key architectural breakthroughs. The integration of the YOLOv8-Pose model for anatomical keypoint anchoring effectively eradicated the compositional drift paradox inherent in traditional bounding-box tracking. Furthermore, the custom trajectory planner, featuring the Symmetric Step Smoothing algorithm, successfully translated raw visual pixel errors into fluid, cinematic motor actuations, completely eliminating mechanical stutter and high-frequency oscillations. The addition of a zero-overhead, temporal-filtered gesture control state machine elevated the gimbal from a passive tracker to an interactive robotic operator. Ultimately, the decisive architectural pivot to a streamlined, bare-metal open-loop SPWM drive ensured that the strict real-time constraints were met without stalling the system, validating the gimbal's robustness and operational reliability.

### 7.2 Future Work

While the current open-loop kinematic architecture exhibits exceptional stability and cinematic smoothness, it inherently operates at a continuous power draw to maintain motor torque, regardless of the physical load.

The primary objective for the next hardware iteration of this project is the implementation of true closed-loop Field-Oriented Control (FOC). This will be achieved by integrating AS5600 high-precision magnetic absolute encoders directly into the pitch and yaw motor assemblies. By feeding real-time, absolute rotor position data back to the lower-level microcontroller, the system will be capable of dynamically calculating the exact optimal vector required to align the magnetic fields. This advanced architectural upgrade will yield three major benefits: it will drastically reduce overall thermal output and power consumption, significantly increase torque efficiency to resist sudden external physical disturbances, and further elevate the micro-stepping precision of the gimbal's movements.

Additionally, future software iterations could explore the integration of multi-target tracking algorithms. By incorporating advanced ID persistence logic (such as ByteTrack), the gimbal could be programmed to memorize specific user IDs, allowing it to intelligently ignore crossing pedestrians and confidently maintain focus on the primary subject in highly complex, crowded environments.

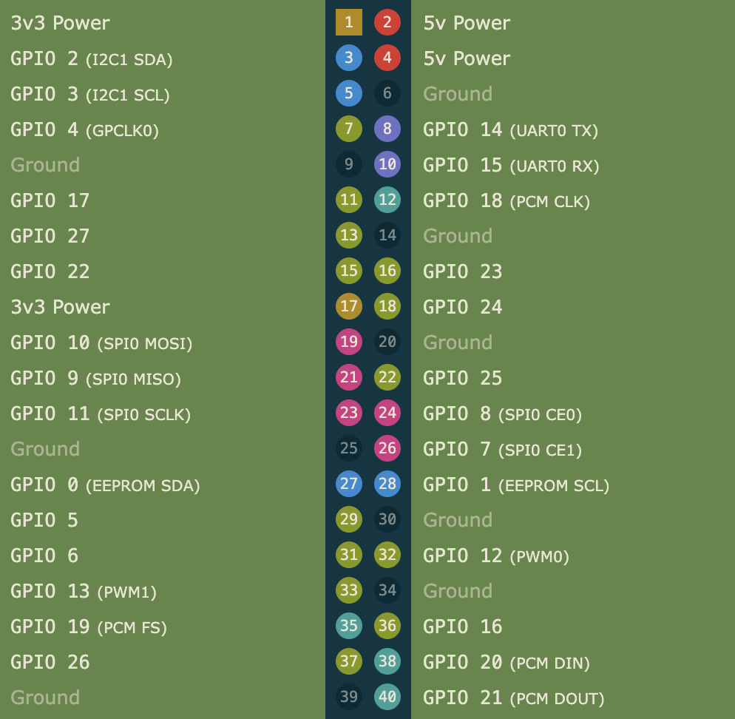
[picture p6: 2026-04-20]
assets/images/pinout connection table 2.png

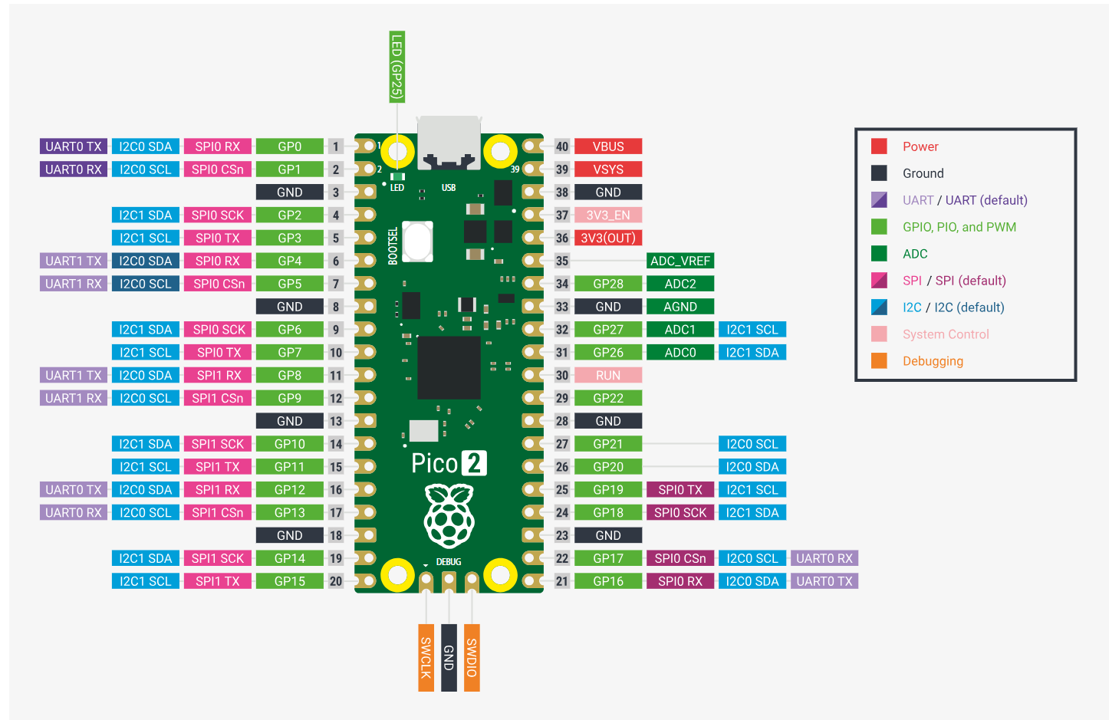
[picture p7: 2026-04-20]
assets/images/pinout connection table 1.png

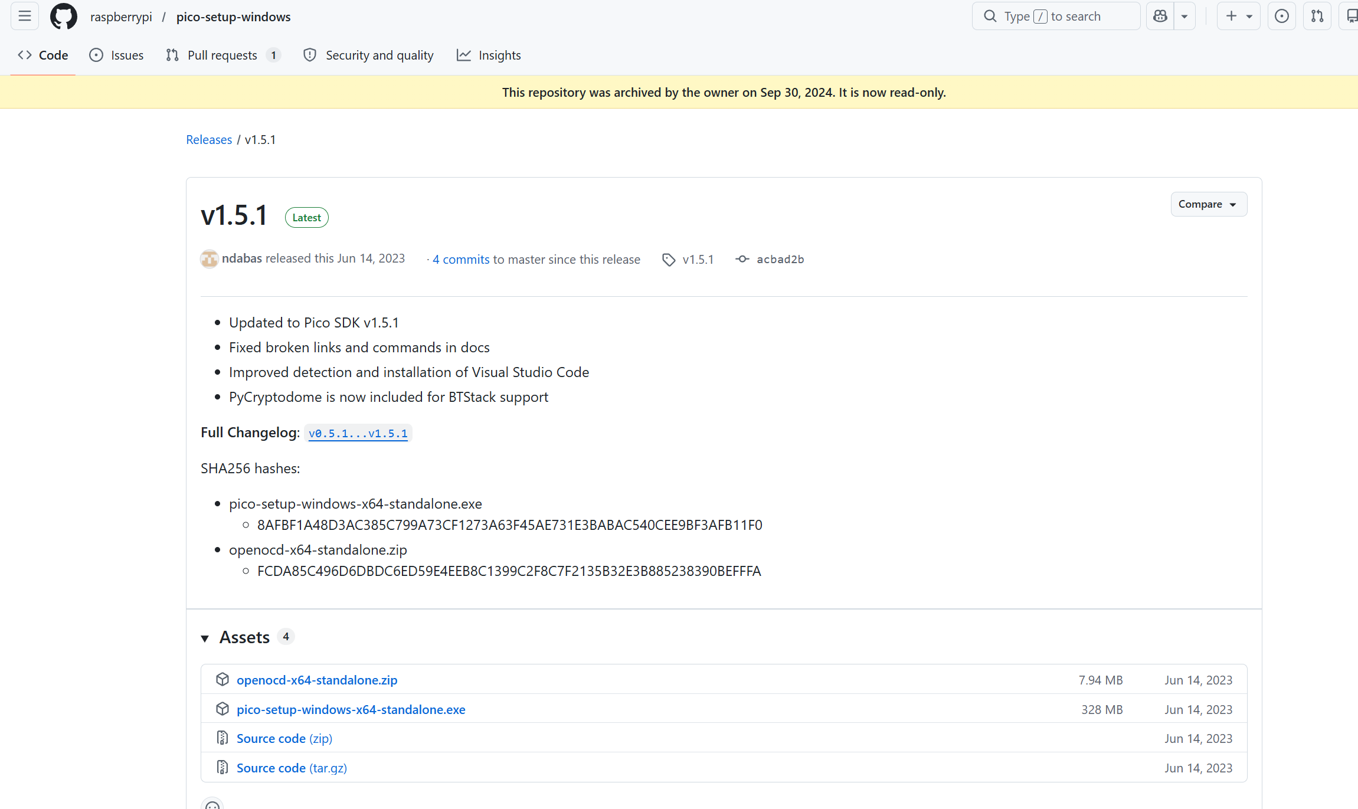
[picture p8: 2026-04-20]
assets/images/pico.png

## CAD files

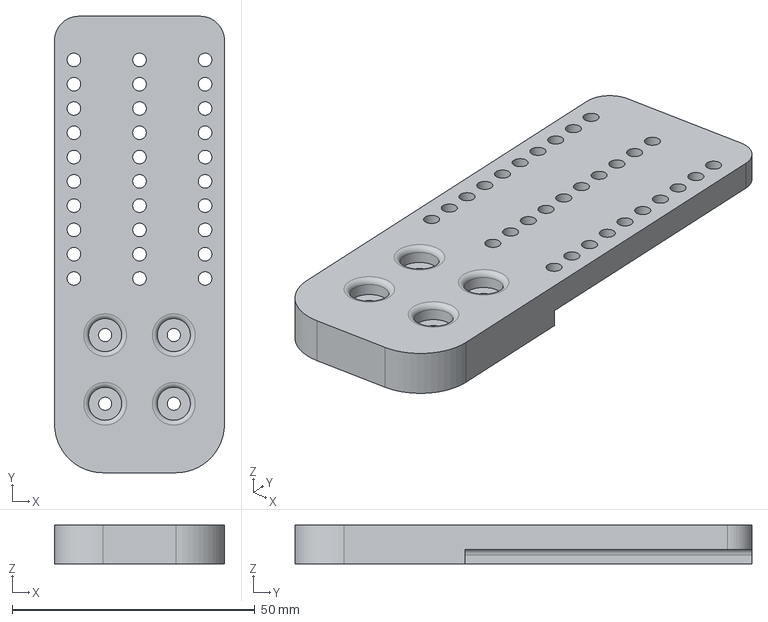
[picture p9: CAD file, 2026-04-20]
assets/3d_models/iris_pitch_motor_bracket.step
35.0 x 94.0 x 8.00 mm

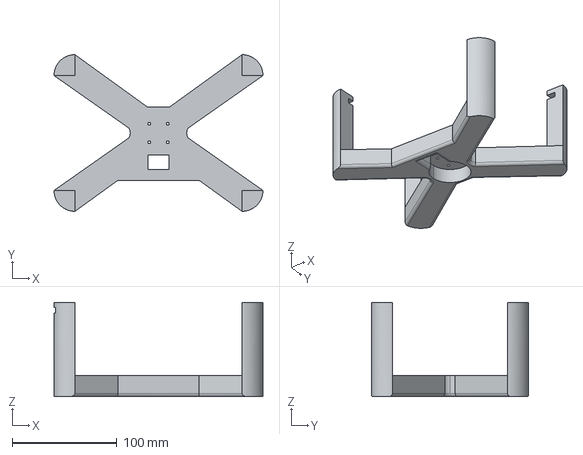
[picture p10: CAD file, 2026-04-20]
assets/3d_models/iris_base_mount.step
200.0 x 150.0 x 90.0 mm

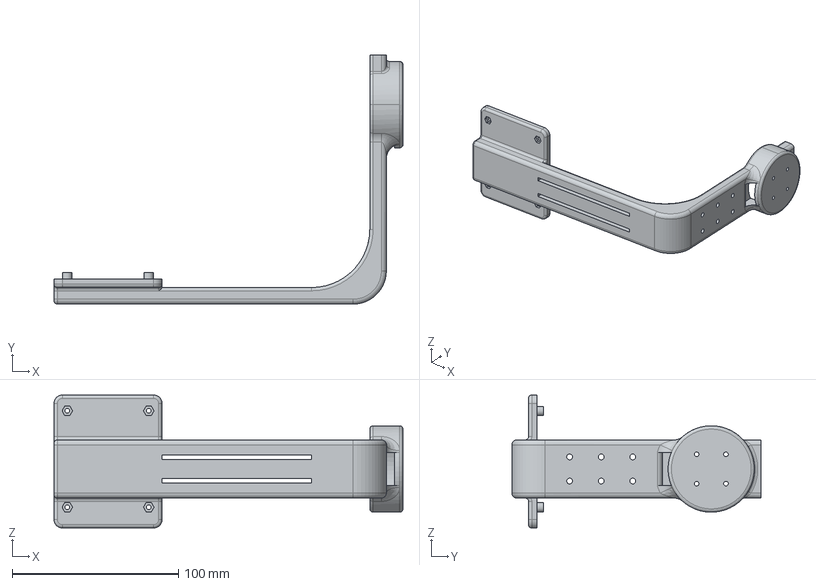
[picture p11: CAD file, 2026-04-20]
assets/3d_models/iris_yaw_arm.step
210.0 x 150.0 x 80.0 mm

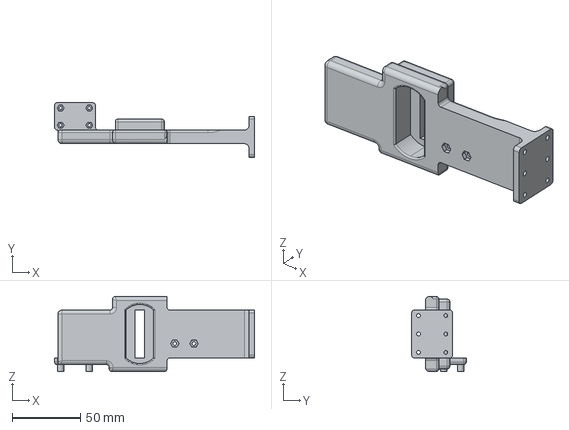
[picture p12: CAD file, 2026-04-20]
assets/3d_models/iris_pitch_camera_plate.step
146.5 x 40.0 x 55.0 mm

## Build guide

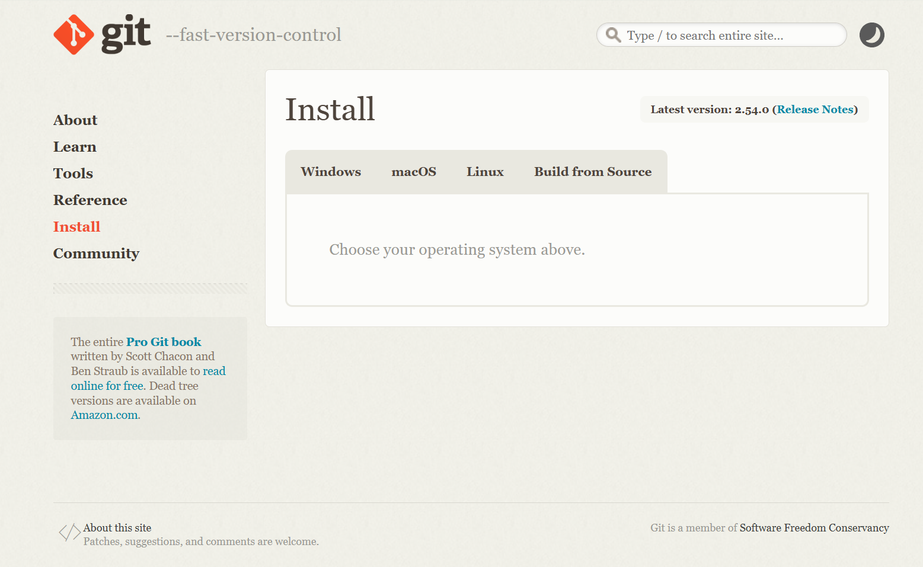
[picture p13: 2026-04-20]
assets/images/git-install.png

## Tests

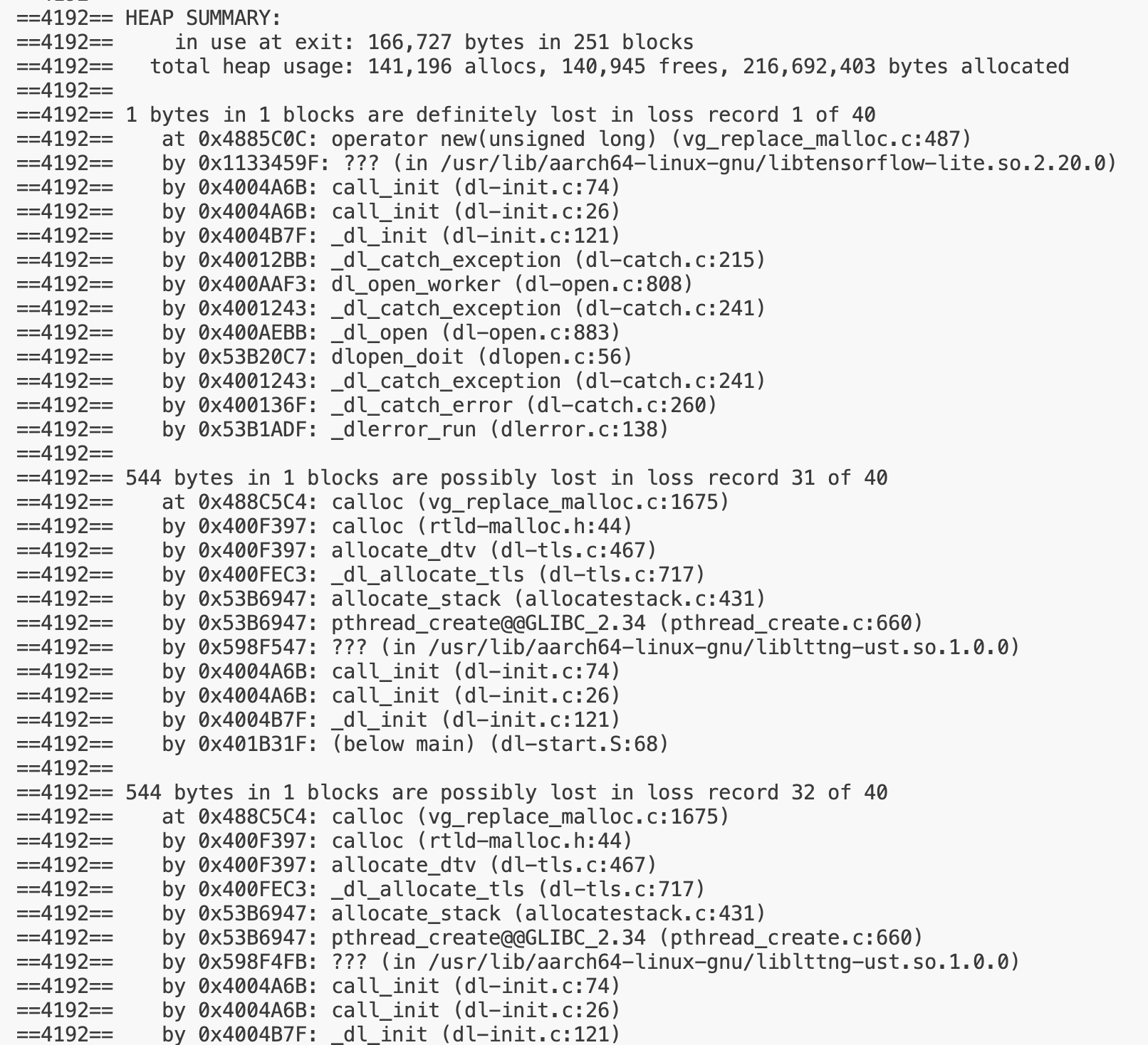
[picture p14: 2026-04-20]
assets/images/test/HEAP Summary.png

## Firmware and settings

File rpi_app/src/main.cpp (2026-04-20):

#include <iostream>
#include <thread>
#include <chrono>
#include <atomic>
#include <csignal>
#include <cmath>
#include <mutex>
#include <iomanip>
#include <algorithm>

#include <ncnn/net.h>
#include <ncnn/mat.h>

#include "utils/SharedState.h"
#include "comm/UartDriver.h"
#include "vision/VisionNode.h"

std::atomic<bool> running(true);
SharedState state;

void signalHandler(int signum) {
    std::cout << "\n[System] Shutting down Iris Gimbal Node...\n";
    running = false;
}

// ==========================================
// Thread 1: Vision Perception (Final Interactive Version with Gesture Switch)
// ==========================================
void visionThread() {
    ncnn::Net yolov8_pose;
    if (yolov8_pose.load_param("../models/yolov8n-pose.param") || 
        yolov8_pose.load_model("../models/yolov8n-pose.bin")) {
        std::cerr << "[Vision] Error: Pose Model missing!" << std::endl;
        return;
    }

    const float X_POLARITY = -1.0f;  
    const float Y_POLARITY = 1.0f; 
    const float TARGET_X = 160.0f;
    const float TARGET_Y = 100.0f; 

    VisionNode camera;
    if (!camera.init()) return;

    std::mutex frame_mutex;
    cv::Mat latest_frame;
    bool has_new_frame = false;

    camera.startCapture([&](const cv::Mat& frame) {
        if (!running) return;
        std::lock_guard<std::mutex> lock(frame_mutex);
        frame.copyTo(latest_frame);
        has_new_frame = true; 
    });

    std::cout << "[Vision] NAKED Mode Active. Tracking: Greedy. Gesture Switch: ON." << std::endl;

    static float last_target_x = TARGET_X;
    static float last_target_y = TARGET_Y;

    // 🌟 Global variables for gesture interaction state machine
    static bool is_tracking = true;         // Main switch for gimbal tracking
    static int gesture_hold_frames = 0;     // Counter for continuous hand-raising frames
    static int cooldown_frames = 0;         // Cooldown lock counter

    while(running) { 
        cv::Mat current_frame;
        {
            std::lock_guard<std::mutex> lock(frame_mutex);
            if (has_new_frame) {
                current_frame = latest_frame;
                has_new_frame = false;
            }
        }
        if (current_frame.empty()) {
            std::this_thread::sleep_for(std::chrono::milliseconds(1));
            continue;
        }

        const int input_size = 640; 
        ncnn::Mat in = ncnn::Mat::from_pixels_resize(current_frame.data, ncnn::Mat::PIXEL_BGR2RGB, 
                                                    current_frame.cols, current_frame.rows, 
                                                    input_size, input_size);
        const float norm_vals[3] = {1/255.f, 1/255.f, 1/255.f};
        in.substract_mean_normalize(0, norm_vals);

        ncnn::Extractor ex = yolov8_pose.create_extractor();
        ex.input("in0", in); 
        ncnn::Mat out;
        ex.extract("out0", out); 

        bool found = false;
        float min_distance = 9999.0f; 
        float best_x = TARGET_X, best_y = TARGET_Y;
        
        // 🌟 Record the hands state of the best target
        float best_lwrist_y = 0.0f, best_lwrist_conf = 0.0f;
        float best_rwrist_y = 0.0f, best_rwrist_conf = 0.0f;

        // Fallback variables
        float fallback_x = TARGET_X, fallback_y = TARGET_Y;
        float fb_lwrist_y = 0.0f, fb_lwrist_conf = 0.0f;
        float fb_rwrist_y = 0.0f, fb_rwrist_conf = 0.0f;
        float max_fallback_conf = 0.0f;

        if (!out.empty() && out.h == 56) {
            for (int i = 0; i < out.w; i++) {
                float score = out.row(4)[i]; 
                if (score > 0.45f) {
                    float nose_x = out.row(5)[i] / 2.0f;
                    float nose_y = out.row(6)[i] / 2.0f;
                    float nose_conf = out.row(7)[i];

                    // Extract wrists (Point 9=LWrist, Point 10=RWrist)
                    float current_lwrist_y = out.row(33)[i] / 2.0f;
                    float current_lwrist_conf = out.row(34)[i];
                    float current_rwrist_y = out.row(36)[i] / 2.0f;
                    float current_rwrist_conf = out.row(37)[i];

                    float current_x = nose_x;
                    float current_y = nose_y;

                    if (nose_conf <= 0.5f) {
                        float l_sh_x = out.row(20)[i]/2.0f, l_sh_y = out.row(21)[i]/2.0f;
                        float r_sh_x = out.row(23)[i]/2.0f, r_sh_y = out.row(24)[i]/2.0f;
                        current_x = (l_sh_x + r_sh_x) / 2.0f;
                        current_y = (l_sh_y + r_sh_y) / 2.0f - 20.0f; 
                    }
                    
                    if (score > max_fallback_conf) {
                        max_fallback_conf = score;
                        fallback_x = current_x; fallback_y = current_y;
                        fb_lwrist_y = current_lwrist_y; fb_lwrist_conf = current_lwrist_conf;
                        fb_rwrist_y = current_rwrist_y; fb_rwrist_conf = current_rwrist_conf;
                    }

                    float dx = current_x - last_target_x;
                    float dy = current_y - last_target_y;
                    float distance = std::sqrt(dx*dx + dy*dy);

                    if (distance < min_distance && distance < 150.0f) {
                        min_distance = distance;
                        best_x = current_x; best_y = current_y;
                        best_lwrist_y = current_lwrist_y; best_lwrist_conf = current_lwrist_conf;
                        best_rwrist_y = current_rwrist_y; best_rwrist_conf = current_rwrist_conf;
                        found = true;
                    }
                }
            }
        }

        if (!found && max_fallback_conf > 0.45f) {
            best_x = fallback_x; best_y = fallback_y;
            best_lwrist_y = fb_lwrist_y; best_lwrist_conf = fb_lwrist_conf;
            best_rwrist_y = fb_rwrist_y; best_rwrist_conf = fb_rwrist_conf;
            found = true;
        }

        // 🌟 Core: Update cooldown lock
        if (cooldown_frames > 0) cooldown_frames--;

        if (found) {
            // 🌟 Core: Gesture interaction judgment logic
            bool is_raising_hand = false;
            // Condition: Left or right wrist confidence is high enough, and wrist Y coordinate is less than nose (above head/nose)
            if ((best_lwrist_conf > 0.5f && best_lwrist_y < best_y) ||
                (best_rwrist_conf > 0.5f && best_rwrist_y < best_y)) {
                is_raising_hand = true;
            }

            if (is_raising_hand && cooldown_frames == 0) {
                gesture_hold_frames++;
                // At 86ms latency, 17 frames is approximately 1.5 seconds
                if (gesture_hold_frames >= 17) { 
                    is_tracking = !is_tracking;     // Toggle state!
                    gesture_hold_frames = 0;
                    cooldown_frames = 35;           // Lock for about 3 seconds, prevent immediate switching

                    std::cout << "\n======================================" << std::endl;
                    if (is_tracking) {
                        std::cout << ">>> [GESTURE] TRACKING RESUMED <<<" << std::endl;
                    } else {
                        std::cout << ">>> [GESTURE] TRACKING PAUSED <<<" << std::endl;
                    }
                    std::cout << "======================================\n" << std::endl;
                } else {
                    // Print progress bar for debugging reference
                    std::cout << "[Gesture] Holding: " << gesture_hold_frames << "/17    \r" << std::flush;
                }
            } else {
                gesture_hold_frames = 0; // Reset immediately when hand is lowered to prevent false triggers
            }

            last_target_x = best_x;
            last_target_y = best_y;

            // 🌟 Core Gate: Send data if in Tracking state, otherwise send 0 to force gimbal to stop
            if (is_tracking) {
                float raw_x = (best_x - TARGET_X) * X_POLARITY;
                float raw_y = (best_y - TARGET_Y) * Y_POLARITY;
                state.updateVision(raw_x, raw_y, true); 
            } else {
                state.updateVision(0.0f, 0.0f, false);
            }

        } else {
            gesture_hold_frames = 0;
            state.updateVision(0.0f, 0.0f, false);
        }
    }
}

// ==========================================
// Thread 2: Control Planning (Retain your tuned parameters)
// ==========================================
void controlThread() {
    const float KP_YAW = 0.005f;   
    const float KP_PITCH = 0.005f; 
    const float DEADZONE = 12.0f;  
    const float MAX_VEL = 0.9f;
    const float SYMMETRIC_STEP = 0.015f; 

    float cur_v_yaw = 0.0f;
    float cur_v_pitch = 0.0f;

    while (running) {
        auto start = std::chrono::steady_clock::now();
        VisionData vd = state.getVision();
        
        float tgt_v_x = 0.0f; 
        float tgt_v_y = 0.0f; 

        if (vd.target_found) {
            float active_err_x = 0.0f;
            if (vd.ex > DEADZONE) active_err_x = vd.ex - DEADZONE;
            else if (vd.ex < -DEADZONE) active_err_x = vd.ex + DEADZONE;

            float active_err_y = 0.0f;
            if (vd.ey > DEADZONE) active_err_y = vd.ey - DEADZONE;
            else if (vd.ey < -DEADZONE) active_err_y = vd.ey + DEADZONE;

            tgt_v_x = active_err_x * KP_YAW;
            tgt_v_y = active_err_y * KP_PITCH;

            tgt_v_x = std::clamp(tgt_v_x, -MAX_VEL, MAX_VEL);
            tgt_v_y = std::clamp(tgt_v_y, -MAX_VEL, MAX_VEL);
        }

        if (cur_v_yaw < tgt_v_x) cur_v_yaw = std::min(cur_v_yaw + SYMMETRIC_STEP, tgt_v_x);
        else if (cur_v_yaw > tgt_v_x) cur_v_yaw = std::max(cur_v_yaw - SYMMETRIC_STEP, tgt_v_x);

        if (cur_v_pitch < tgt_v_y) cur_v_pitch = std::min(cur_v_pitch + SYMMETRIC_STEP, tgt_v_y);
        else if (cur_v_pitch > tgt_v_y) cur_v_pitch = std::max(cur_v_pitch - SYMMETRIC_STEP, tgt_v_y);

        state.updateCommand(cur_v_yaw, cur_v_pitch);
        std::this_thread::sleep_until(start + std::chrono::milliseconds(10));
    }
}

// ==========================================
// Thread 3: UART Dispatch
// ==========================================
void uartThread() {
    UartDriver uart;
    if (!uart.init("/dev/serial0")) return;

    while (running) {
        auto start = std::chrono::steady_clock::now();
        VelocityCommand cmd = state.getCommand();
        uart.sendVelocity(cmd.pitch_vel, cmd.yaw_vel);
        std::this_thread::sleep_until(start + std::chrono::milliseconds(20));
    }
}

int main() {
    std::signal(SIGINT, signalHandler);
    std::cout << "==================================================" << std::endl;
    std::cout << "[System] Iris Gimbal Active (Gesture Engine v1.0)" << std::endl;
    std::cout << "==================================================" << std::endl;

    std::thread t1(visionThread);
    std::thread t2(controlThread);
    std::thread t3(uartThread);

    while (running) {
        std::this_thread::sleep_for(std::chrono::milliseconds(500));
    }

    if (t1.joinable()) t1.join();
    if (t2.joinable()) t2.join();
    if (t3.joinable()) t3.join();
    
    return 0;
}

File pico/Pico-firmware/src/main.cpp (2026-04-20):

#include <SimpleFOC.h>
#include "pico/stdlib.h"
#include "hardware/timer.h"
#include "hardware/clocks.h" 
#include <math.h>
#include "../include/UART_Parser.h"

// ==============================================================================
// 1. Math Utility Class (静态数学辅助类：封装查表算法，避免全局函数污染)
// ==============================================================================
class FastMath {
private:
    static float sin_lut[256];
    static bool initialized;

public:
    static void init() {
        if (initialized) return;
        for (int i = 0; i < 256; i++) {
            sin_lut[i] = sinf((float)i * 6.2831853f / 256.0f);
        }
        initialized = true;
    }

    static inline float fast_sin(float angle) {
        float angle_norm = fmodf(angle, 6.2831853f);
        if (angle_norm < 0) angle_norm += 6.2831853f;
        int index = (int)(angle_norm * 40.74366f); 
        return sin_lut[index & 0xFF];
    }
};

// 初始化静态成员变量
float FastMath::sin_lut[256];
bool FastMath::initialized = false;

// ==============================================================================
// 2. Gimbal Motor Class (云台电机核心类：彻底消灭 #define 和散装全局变量)
// ==============================================================================
class GimbalMotor {
private:
    // 硬件对象与物理参数 (私有化，禁止外部直接篡改)
    BLDCDriver3PWM driver;
    int en_pin;
    float pole_pairs;
    float voltage_limit;
    
    // 运动状态与平滑器内存
    float smooth_vel;
    float current_angle;
    float current_vol;

public:
    // 构造函数：取代原本的宏定义，实例化时动态注入引脚和参数
    GimbalMotor(int in1, int in2, int in3, int en, float vol_limit, float pp)
        : driver(in1, in2, in3, en), en_pin(en), pole_pairs(pp), voltage_limit(vol_limit),
          smooth_vel(0.0f), current_angle(0.0f), current_vol(0.0f) {}

    // 硬件初始化
    void init(float voltage_supply) {
        gpio_init(en_pin);
        gpio_set_dir(en_pin, GPIO_OUT);
        gpio_put(en_pin, 1);

        driver.voltage_power_supply = voltage_supply;
        driver.init();
        driver.enable();
    }

    // 软启动逻辑：返回 true 代表当前电机的电压已达上限，软启动完成
    bool processSoftStart(float dt) {
        if (current_vol < voltage_limit) {
            current_vol += 2.0f * dt; // Rise rate: 2V/s
            if (current_vol >= voltage_limit) current_vol = voltage_limit;
        }
        return (current_vol >= voltage_limit);
    }

    // 核心 SPWM 运算与输出
    void updateSPWM(float target_vel, float dt, float U_center) {
        // Trapezoidal acceleration limiter
        const float max_accel = 6.0f; 
        const float max_delta_v = max_accel * dt; 

        if (target_vel > smooth_vel + max_delta_v) smooth_vel += max_delta_v; 
        else if (target_vel < smooth_vel - max_delta_v) smooth_vel -= max_delta_v; 
        else smooth_vel = target_vel; 

        // Continuous full-power signal output
        current_angle += smooth_vel * dt;
        float elec_angle = current_angle * pole_pairs;
        
        driver.setPwm(
            U_center + current_vol * FastMath::fast_sin(elec_angle),
            U_center + current_vol * FastMath::fast_sin(elec_angle - 2.0944f), 
            U_center + current_vol * FastMath::fast_sin(elec_angle - 4.1888f)  
        );
    }
};

// ==============================================================================
// 3. System Globals (系统级全局变量：保留给 UART_Parser.cpp 进行跨文件通信)
// ==============================================================================
const float VOLTAGE_SUPPLY = 12.0f;
volatile bool is_soft_starting = true;

// 警告：这些变量保留全局是因为底层的 UART_Parser 可能使用 extern 引用了它们
// 若强行封装会导致外部解析器无法写入数据。在工程中，这称为“合理的通信桥梁妥协”。
volatile float target_pitch_vel = 0.0f;
volatile float target_yaw_vel   = 0.0f; 
volatile uint32_t raw_rx_byte_count = 0;
volatile uint32_t err_cksm = 0;
volatile uint32_t err_tail = 0;

// 实例化面向对象实体 (Instantiate Objects)
GimbalMotor pitchMotor(2, 4, 6, 16, 4.5f, 11.0f);
GimbalMotor yawMotor(10, 11, 12, 15, 4.5f, 11.0f);
UART_Parser uart_parser;

// ==============================================================================
// 4. ISR (硬件定时器中断：逻辑被极限简化，仅负责调用对象的方法)
// ==============================================================================
bool spwm_timer_callback(struct repeating_timer *t) {
    const float dt = 0.002f; 
    const float U_center = VOLTAGE_SUPPLY / 2.0f;

    // 1. 面向对象的软启动检查
    if (is_soft_starting) {
        bool pitch_ready = pitchMotor.processSoftStart(dt);
        bool yaw_ready = yawMotor.processSoftStart(dt);
        if (pitch_ready && yaw_ready) {
            is_soft_starting = false; 
        }
    }

    // 2. 指挥对象执行运算（替代原本的一大坨流水账代码）
    pitchMotor.updateSPWM(target_pitch_vel, dt, U_center);
    yawMotor.updateSPWM(target_yaw_vel, dt, U_center);

    return true; 
}

// ==============================================================================
// 5. Main 
// ==============================================================================
int main() {
    stdio_init_all();
    FastMath::init(); // 初始化静态数学类
    sleep_ms(2000); 

    set_sys_clock_khz(133000, true);

    // 面向对象初始化
    pitchMotor.init(VOLTAGE_SUPPLY);
    yawMotor.init(VOLTAGE_SUPPLY);

    uart_parser.init(uart0, 0, 1, 115200);

    struct repeating_timer timer;
    add_repeating_timer_us(-2000, spwm_timer_callback, NULL, &timer);

    uint32_t last_print_time = 0;

    while (true) {
        uint32_t now = to_ms_since_boot(get_absolute_time());
        uint32_t last_rx = uart_parser.getLastRxTime();

        if (now - last_print_time >= 200) {
            last_print_time = now;
            if ((now - last_rx) > 500) {
                target_pitch_vel = 0.0f;
                target_yaw_vel   = 0.0f;
                printf("[SAFE] Timeout! Bytes: %u | ErrCK: %u\n", raw_rx_byte_count, err_cksm);
            } else {
                printf("[LIVE] P:%.2f Y:%.2f | ErrCK: %u\n", target_pitch_vel, target_yaw_vel, err_cksm);
            }
        }
    }
    return 0;
}

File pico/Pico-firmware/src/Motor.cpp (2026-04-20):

#include "../include/Motor.h"

// Constructor
Motor::Motor(int phA, int phB, int phC, int en) {
    driver = new BLDCDriver3PWM(phA, phB, phC, en);
    // The GM3506 gimbal motor typically has 11 pole pairs. In open-loop mode, the number of pole pairs must be specified.
    motor = new BLDCMotor(11); 
}

void Motor::init() {
    // 1. Driver board configuration (assuming you are using a 12V power battery supply)
    driver->voltage_power_supply = 12.0f; 
    driver->init();
    motor->linkDriver(driver);

    // 2.Core: open-loop safety limits (must never be removed!)
    motor->voltage_limit = 5.0f;   // Limit the maximum phase voltage to 3V to prevent overheating and burnout in open-loop operation
    motor->velocity_limit = 20.0f; // Limit the maximum rotational speed to 20 rad/s

    // 3. Configure for open-loop velocity control mode
    motor->controller = MotionControlType::velocity_openloop;

    // 4. Bypass the sensor and initialize directly
    motor->init();
    
    // Set the initial velocity to 0
    motor->target = 0.0f;
}

void Motor::setTargetVelocity(float target_vel) {
    motor->target = target_vel;
}

void Motor::loopFOC() {
    // In open-loop mode, loopFOC is effectively empty, but it is kept to maintain architectural consistency
    motor->loopFOC();
}

void Motor::move() {
    // Open-loop core: forcibly output the three-phase sine wave purely based on microsecond-level timestamps
    motor->move();
}

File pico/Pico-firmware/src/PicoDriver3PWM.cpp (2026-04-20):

#include <SimpleFOC.h>
#include <stdio.h> // 🌟 Add the standard input/output header files to ensure printf syntax is fully safe
#include "hardware/pwm.h"
#include "hardware/clocks.h"
#include "hardware/gpio.h"

// Struct for caching pins and count values
struct Pico3PWMParams {
    int pinA;
    int pinB;
    int pinC;
    uint32_t wrap; 
};

void* _configure3PWM(long pwm_frequency, const int pinA, const int pinB, const int pinC) {
    if(pinA == NOT_SET || pinB == NOT_SET || pinC == NOT_SET) return nullptr;

    int pins[3] = {pinA, pinB, pinC};
    uint32_t sys_clk = clock_get_hz(clk_sys);
    
    // If no frequency is specified, set the default to 25 kHz
    if(pwm_frequency == 0 || pwm_frequency == NOT_SET) pwm_frequency = 25000;
    
    uint32_t wrap = sys_clk / pwm_frequency;
    if (wrap > 65535) wrap = 65535; 

    // Configure the Pico native PWM
    for (int i = 0; i < 3; i++) {
        gpio_set_function(pins[i], GPIO_FUNC_PWM);
        uint slice_num = pwm_gpio_to_slice_num(pins[i]);
        pwm_set_wrap(slice_num, wrap);
        pwm_set_clkdiv(slice_num, 1.0f);
        pwm_set_enabled(slice_num, true);
    }

    // Allocate memory to store the pins and count values, then return it to the driver layer
    Pico3PWMParams* params = new Pico3PWMParams();
    params->pinA = pinA;
    params->pinB = pinB;
    params->pinC = pinC;
    params->wrap = wrap; // Cache the count value to avoid hardware pointer pitfalls
    return params;
}

void _writeDutyCycle3PWM(float dc_a, float dc_b, float dc_c, void* params) {
    if(params == nullptr) return;
    Pico3PWMParams* p = (Pico3PWMParams*)params;

    // 🌟  Ultimate scout (tripwire): directly intercept the final duty cycle (0.0 ~ 1.0) computed by the SimpleFOC core
    // Reduce the print frequency to prevent the serial port from being saturated and causing motor stuttering
    static int count = 0;
    

    // Completely abandon dangerous hardware pointers and use the cached p->wrap directly for safe conversion!
    pwm_set_gpio_level(p->pinA, (uint16_t)(dc_a * p->wrap));
    pwm_set_gpio_level(p->pinB, (uint16_t)(dc_b * p->wrap));
    pwm_set_gpio_level(p->pinC, (uint16_t)(dc_c * p->wrap));
}

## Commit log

2026-02-21 feat: 初始化 Pico 纯 C++ CMake 编译框架，跑通首个 FOC 通信状态机
2026-02-22 feat(comm): implement UART communication protocol V1.1 and test sender
2026-02-23 feat(vision): implement camera capture with microsecond timestamping
2026-02-26 feat(pico): migrate UART communication to UART1 (GP4/GP5) and implement V1.2 protocol
2026-04-19 refactor: adapt Arduino HAL and time utils for Pico 2 compatibility
2026-04-19 feat: reconstruct UART parser with high priority IRQ to stabilize 115200 baud rate
    [UART_Parser.cpp]
2026-04-19 fix: optimize 3-phase PWM driver and enhance SimpleFOC core integration
    [Motor.cpp, PicoDriver3PWM.cpp]
2026-04-19 feat: integrate SPWM logic with soft-start and slew rate limiter to eliminate motor jitter
    [main.cpp]
2026-04-19 chore: refactor workspace into monorepo structure (rpi_app & pico_firmware)
    [model.ncnn.param, yolov8n.param]
2026-04-19 fix: restore hardware driver implementation and correct CMake configuration
2026-04-19 refactor: isolate Pico code into Pico-firmware directory prior to merge
2026-04-20 feat(core): fix hardware axis cross-coupling and polarities, establish stable P-control baseline
    [main.cpp]
2026-04-20 new yolo models
    [yolov8n-pose.param]
2026-04-20 Fix CMake syntax error and upgrade CI path detection
    [main.cpp]
2026-04-20 feat: upgrade to YOLOv8-pose, implement fast gesture control switch with mechanical nodding feedback, and fix symmetric smoothing for yaw axis
    [iris_base_mount.step, iris_pitch_camera_plate.step, iris_pitch_motor_bracket.step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]
2026-04-20 system flowchat added
